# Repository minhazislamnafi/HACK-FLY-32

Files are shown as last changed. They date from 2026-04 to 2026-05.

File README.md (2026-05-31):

# HACK FLY 32 (3 inch fpv drone using esp32 s3)

A compact 3-inch 3D printed FPV drone designed for efficiency, stability, and extended flight time. This project features a custom-built flight controller, ExpressLRS (ELRS) communication, and GPS support, all running on Betaflight firmware.






HACK FLY ZINE(2)

**[Zine link](/docs/ZINE/HACK%20FLY%20ZINE.pdf)**

⚠️ Disclaimer
The use and operation of this drone may require licenses in certain countries. This project is experimental and provided without any guarantee of safety or reliability and it's under the [CERN Open Hardware Licence version 2-Strongly reciprocal ](/license), and the firmware ESP-FLY is under the MIT license.

USE AT YOUR OWN RISK.

# Specifications

Frame Size: 3-inch.

Motors: 1104 – 4300KV.

Propeller: Gemfan 3018 bi-blade.

Battery Support: 2S – 3S LiPo.

suggested battery: (900-1500)mah 3s lipo.

Flight Controller: Custom-designed FC.

Firmware: Betaflight.

RC Protocol: ExpressLRS (ELRS)

Navigation: GPS supported.

gps compatibility: any 15*15mm gps (Hglrs m100 mini suggested)

Use Case: Long-range FPV, exploration, and experimental flight testing.

# Why HACK FLY?

A custom hardware and PCB that gives you your own way to add spice to it.
Also compatible with BetaFlight (you can achieve very agile and stable flight characteristics). Supports all types of Radio RX protocols: PPM, SBUS, IBUS, and CRSF Receivers.
If you combine it with a high-performance 18650 Li-ion battery (like Molicel PB28A,Eve 30pl,Ampace jp30 or Sony vt6), you can get over 10 minutes of flight time.

Who didn't want his drone to be repairable? The 3D-printed frame gives you that flexibility.
Break the frame in a crash? Just print another. Cost? less than 1$ even if you use PETG-CF.

# Documentation
In this repository, you can find 3D printable STL files, Garber and all the other
files to build your own flight controller and Drone frame. 
For flashing the latest Betaflight to the Flight controller visit rtlopez/esp-fc repo- 
**https://github.com/rtlopez/esp-fc**.

Join our **[Discord Channel](https://discord.gg/Ff5Q2nz4)** to get any kind of help.

# Quick Start

## Requirements

## Hardware:

* Seeed Studio Xiao ESP32 S3(https://www.seeedstudio.com/XIAO-ESP32S3-p-5627.html)
* 1104 4300kv mottor x4 (https://s.click.aliexpress.com/e/_c4sG0n0N)
* 2-3S micro 8A ESC x4 (https://s.click.aliexpress.com/e/_c4ShBcjr)
> [!IMPORTANT]
> **If you also want build your own 4in1 esc**, Visit this repo- **https://github.com/minhazislamnafi/Nano-2-3s-AM32-ESC**.
* Gemfan 3018 bi-blade × 2 pair (https://s.click.aliexpress.com/e/_c34qvZlJ)
* Hglrc m100 mini GPS (https://s.click.aliexpress.com/e/_c4F9Fw8h)
* HGLRC Zeus Nano VTX 350mW (https://s.click.aliexpress.com/e/_c3wNfnSD)
* 2.54mm Round Hole Needle Female & Male Pin Header (https://s.click.aliexpress.com/e/_c327hfoV)

**Components:**

* Mpu6050M QFN-24 (https://s.click.aliexpress.com/e/_c2JBpdQt)
* 0402 10uH inductor (https://s.click.aliexpress.com/e/_c3vbFmHj)
* Some 0603 size Resistors and capacitors [**Checkout Bill of material**](/Flight%20Controller/PCB/BOM_HACK_FLY_V1.2_2026-04-11.csv)
(https://a.aliexpress.com/_c3XHJm1T)
* 0805 size red & green led ×2
(https://s.click.aliexpress.com/e/_c3fRfz0V)

## For detailed parts list and prices follow [BOM](docs/Bill%20of%20material/BOM.md) ##

## PCB

Use JLCPCB if you're in ASIA or PCBWAY if you're in America. Also, find what manufacturer is better for you. 
If you just want to get Flight controller PCB then use this [**GERBER file**](/Flight%20Controller/PCB/Gerber_HACK_FLY_PCB_V1.2_2026-04-11.zip). Download it and place order.
Or if you just want to build your own PCB, then follow this [**Schematic**](/Flight%20Controller/PCB/Schematic_HACK_FLY_2026-04-11.svg).
fc 2 bg2

## 3D printed parts

1000042196-Photoroom

## Full Onshape CAD [link](https://cad.onshape.com/documents/91570ca427478f6ae70e01eb/w/492acaa76972d9ee5b32506f/e/992fe092f0691e5ff67f2b14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)/[Full assembly](https://cad.onshape.com/documents/91570ca427478f6ae70e01eb/w/492acaa76972d9ee5b32506f/e/0d19368f0521a092eb10a81c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)

To print all the parts for the HACK FLY frame, please **USE-**

**PETG or ABS** - [Top plate](/Drone%20Frame/Top%20Plate/Top%20plate.stl), [Bottom plate](/Drone%20Frame/Bottom%20plate).(**better to use PETG-CF**)

**TPU** - [Camera mount](/Drone%20Frame/Camera%20Mount/Camera%20mount%20right.stl), [GPS mount](/Drone%20Frame/GPS%20mount/GPS%20mount.stl), [VTXantena mount](/Drone%20Frame/Vtx%20antena%20mount/Antenna%20mount.stl).

## Wiring Diagram ##
wiring_diagram

## AFTER EVERYTHING IS DONE SOURCING, FOLLOW THESE STEPS ##

**1. Spend some money $$ to buy the parts mentioned in [BOM](docs/Bill%20of%20material/BOM.md).**

**2. Order the Flight controller PCB using this [GERBER file](/Flight%20Controller/PCB/Gerber_HACK_FLY_PCB_V1.2_2026-04-11.zip).**

**3. Solder the SMD components of the PCB by hand ;) Or just order the PCBs with SMT services.**

**4. Using the wiring diagram, solder the ESCs and battery connector to the PCB.**

**5. crucial step: assemble everything. ( I will add every assembly step, once I have built IRL:)**

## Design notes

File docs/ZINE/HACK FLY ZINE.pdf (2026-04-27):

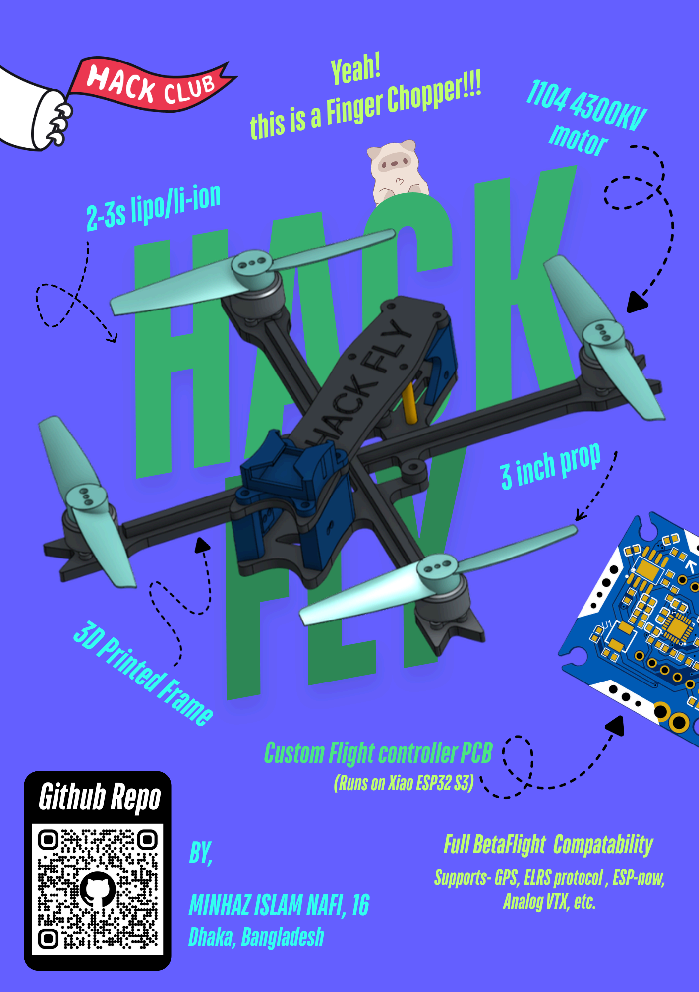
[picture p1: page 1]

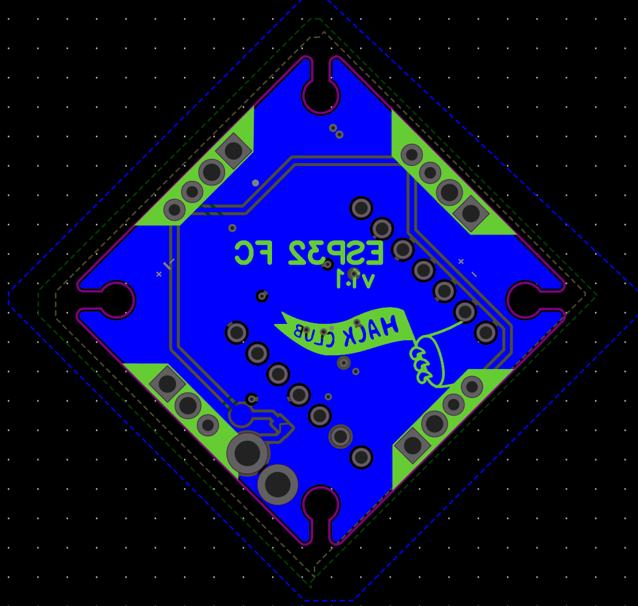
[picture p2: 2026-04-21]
docs/Images/FC_PCB_back.png

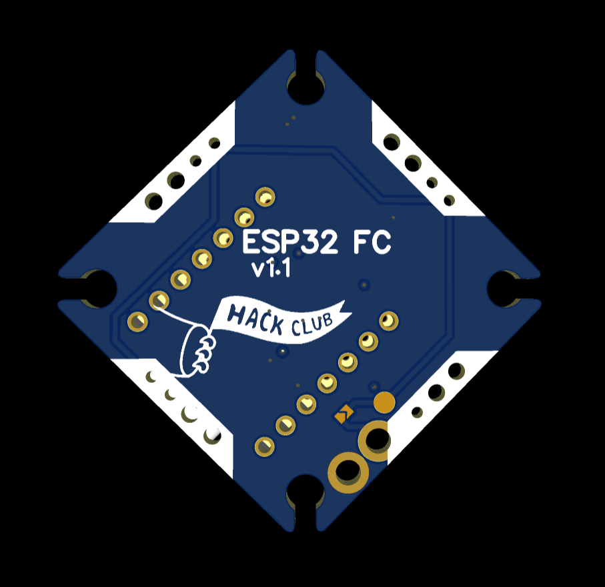
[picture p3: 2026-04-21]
docs/Images/FC_PCB_render_back.png

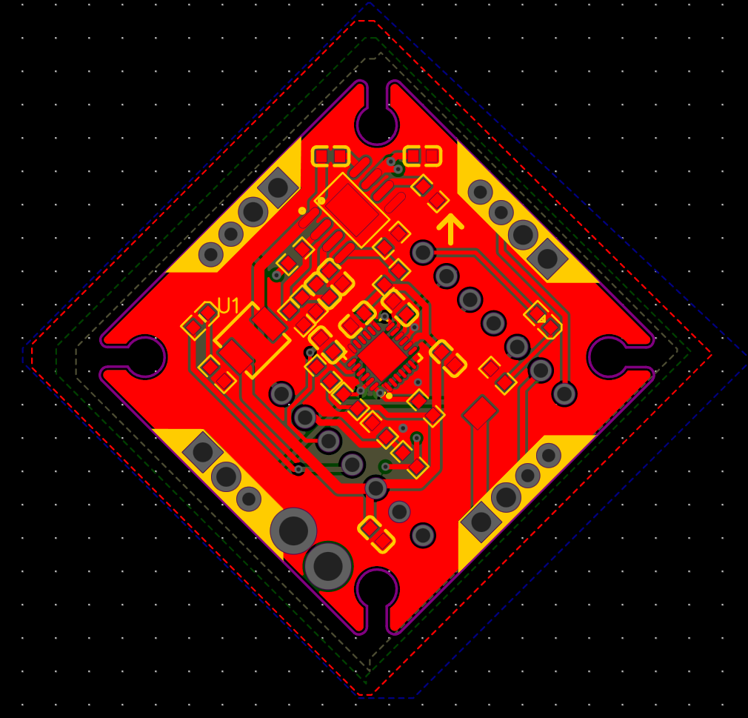
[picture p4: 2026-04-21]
docs/Images/FC_PCB_front.png

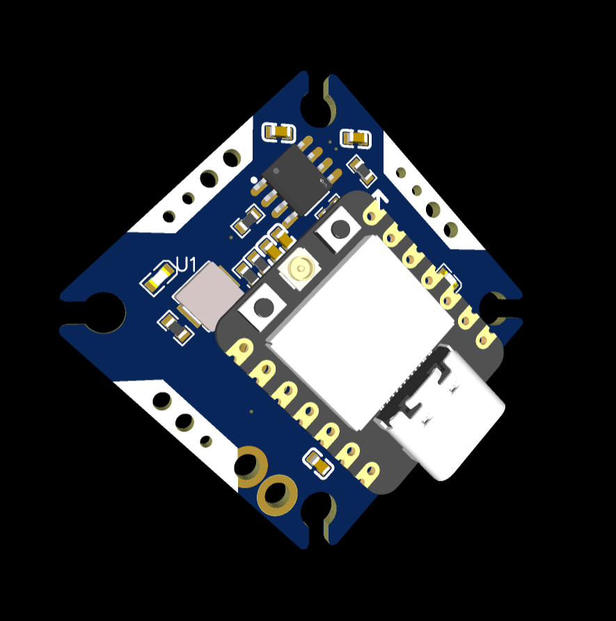
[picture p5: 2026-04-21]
docs/Images/FC_PCB_render_front.png

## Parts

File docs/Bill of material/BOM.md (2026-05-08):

# BOM #

The quantity of parts marked **(*)** is the lowest they sell. This is not the actual requirement quantity.

| Name | Qty | footprint | Source | price (total)|
| --- | :---: | :---: | :---: | :---: |
|  |  |  |  |  |
|  |  |  |  |  |
| **(For flight controller)** |  |  |  |  |
|  |  |  |  |  |
| `Seeed Studio Xiao ESP32 S3` | 1 | | [Seeed Studio](https://www.seeedstudio.com/XIAO-ESP32S3-p-5627.html) | 7.50$ |
| `Mpu6050M QFN-24` | *2 | QFN-24 | [AliExpress](https://s.click.aliexpress.com/e/_c2JBpdQt)  | 3.40$ |
| `MP1584EN-LF` | 1 | SOIC-8 | [AliExpress](https://s.click.aliexpress.com/e/_c4m1MzqZ) | 3.00$ |
| `2.54mm Round Hole Needle Female & Male Pin Header` | 2 | 2.54mm*40p | [AliExpress](https://s.click.aliexpress.com/e/_c327hfoV) | 2.30$  |
| `0402 10uH inductor` | *10 | L0402 | [AliExpress](https://s.click.aliexpress.com/e/_c3vbFmHj) | 1.80$ |
| ``100nf cap`` | *50 | C0603 | [AliExpress](https://s.click.aliexpress.com/e/_c2zBG1P7) | 0.90$ |
| ``10uf cap``| *50 | C0603 | [AliExpress](https://s.click.aliexpress.com/e/_c3JfbJJL) | 1.90$ |
| ``220pf cap`` | *50 | C0603 | [AliExpress](https://s.click.aliexpress.com/e/_c2zBG1P7) | 0.90$ |
| ``Red &green LED`` | *200 | 0603 | [AliExpress](https://s.click.aliexpress.com/e/_c2uf5xmZ)  | 1.20$ |
| ``200`` | *100 | R0603 | [AliExpress](https://s.click.aliexpress.com/e/_c3cSR54l) | 0.65$ |
| ``10K`` | *100 | R0603 | [AliExpress](https://s.click.aliexpress.com/e/_c3cSR54l) | 0.65$ |
| ``100K`` | *100 | R0603 | [AliExpress](https://s.click.aliexpress.com/e/_c3cSR54l) | 0.65$ |
| ``200K`` | *100 | R0603 | [AliExpress](https://s.click.aliexpress.com/e/_c3cSR54l) | 0.65$ |
| ``24.9K`` | *100 | R0603 | [AliExpress](https://s.click.aliexpress.com/e/_c3cSR54l) | 0.65$ |
| ``64.1K`` | *100 | R0603 | [AliExpress](https://s.click.aliexpress.com/e/_c3cSR54l) | 0.65$ |
| ``124K`` | *100 | R0603 | [AliExpress](https://s.click.aliexpress.com/e/_c3cSR54l) | 0.65$ |
| ``40.2K`` | *100 | R0603 | [AliExpress](https://s.click.aliexpress.com/e/_c3cSR54l) | 0.65$ |
|  |  |  |  |  |
|  |  |  |  |  |
| **(For Drone it self)** |  |  |  |  |
|  |  |  |  |  |
| `1104 4300kv mottor` | 4 | | [AliExpress](https://s.click.aliexpress.com/e/_c4sG0n0N)  | 11.72$ |
| `2-3S micro 8A ESC` | 4 | | [AliExpress](https://s.click.aliexpress.com/e/_c4ShBcjr)  | 6.92$ |
| `Gemfan 3018 bi-blade` | 4 pair | | [AliExpress](https://s.click.aliexpress.com/e/_c34qvZlJ ) | 7.5$ |
| `2.4Ghz ELRS RX` | 1 |  | [AliExpress](https://a.aliexpress.com/_c4OytxWf) | 11.5 |
| `Hglrc m100 mini GPS` | 1 | | [AliExpress](https://s.click.aliexpress.com/e/_c4F9Fw8h)  | 15.6$ |
| `HGLRC Zeus Nano VTX 350mW` | 1 | | [AliExpress](https://s.click.aliexpress.com/e/_c3wNfnSD)| 26.8$ |
| `2mm*15mm Female to Female thread Brass Round Standoff` | *20 | | [ AliExpress](https://s.click.aliexpress.com/e/_c4UTr2UN)  | 1.95$ |
| `M1.4*6mm Cross Phillips Flat Head Countersunk Head Screw` | *100  | | [AliExpress](https://s.click.aliexpress.com/e/_c2ynEA9r ) | 0.85$ |
| `M2*6mm Phillips Truss Mushroom Head Screw` | *20 | | [AliExpress](https://s.click.aliexpress.com/e/_c3dtilIl) | 1.08$|
| `M2*12mm Harden Allen Hex Hexagon Screw` | *50 | | [AliExpress](https://s.click.aliexpress.com/e/_c34U4h6V)| 2.80$ |
|  |  |  | | |
|  |  |  | | |
| **PCB Manufacturing** | *5 |  | [JLCPCB](https://cart.jlcpcb.com/quote) | 2$ +shiping|
|  |  |  | | |
| **3D printing** | 1 |  | local vendor | ~2$ |
|  |  |  | | |
|  |  |  | | |
|  |  | **Esteemed Cost** | Around(**~105$**) | |

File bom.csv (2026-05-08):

Name | Qty | Footprint | Source | Unit Price | Price (total)
(For flight controller)
Seeed Studio Xiao ESP32 S3 | 1 |  | https://www.seeedstudio.com/XIAO-ESP32S3-p-5627.html | 7.50 | 7.50
Mpu6050M QFN-24 | 2 | QFN-24 | https://s.click.aliexpress.com/e/_c2JBpdQt | 1.70 | 3.40
MP1584EN-LF | 1 | SOIC-8 | https://s.click.aliexpress.com/e/_c4m1MzqZ | 3.00 | 3.00
2.54mm Round Hole Needle Female & Male Pin Header | 2 | 2.54mm*40p | https://s.click.aliexpress.com/e/_c327hfoV | 1.15 | 2.30
0402 10uH inductor | 10 | L0402 | https://s.click.aliexpress.com/e/_c3vbFmHj | 0.18 | 1.80
100nf cap | 50 | C0603 | https://s.click.aliexpress.com/e/_c2zBG1P7 | 0.018 | 0.90
10uf cap | 50 | C0603 | https://s.click.aliexpress.com/e/_c3JfbJJL | 0.038 | 1.90
220pf cap | 50 | C0603 | https://s.click.aliexpress.com/e/_c2zBG1P7 | 0.018 | 0.90
Red & green LED | 200 | 0603 | https://s.click.aliexpress.com/e/_c2uf5xmZ | 0.006 | 1.20
200 resistor | 100 | R0603 | https://s.click.aliexpress.com/e/_c3cSR54l | 0.0065 | 0.65
10K resistor | 100 | R0603 | https://s.click.aliexpress.com/e/_c3cSR54l | 0.0065 | 0.65
100K resistor | 100 | R0603 | https://s.click.aliexpress.com/e/_c3cSR54l | 0.0065 | 0.65
200K resistor | 100 | R0603 | https://s.click.aliexpress.com/e/_c3cSR54l | 0.0065 | 0.65
24.9K resistor | 100 | R0603 | https://s.click.aliexpress.com/e/_c3cSR54l | 0.0065 | 0.65
64.1K resistor | 100 | R0603 | https://s.click.aliexpress.com/e/_c3cSR54l | 0.0065 | 0.65
124K resistor | 100 | R0603 | https://s.click.aliexpress.com/e/_c3cSR54l | 0.0065 | 0.65
40.2K resistor | 100 | R0603 | https://s.click.aliexpress.com/e/_c3cSR54l | 0.0065 | 0.65
(For Drone itself)
1104 4300kv motor | 4 |  | https://s.click.aliexpress.com/e/_c4sG0n0N | 2.93 | 11.72
2-3S micro 8A ESC | 4 |  | https://s.click.aliexpress.com/e/_c4ShBcjr | 1.73 | 6.92
Gemfan 3018 bi-blade | 4 pair |  | https://s.click.aliexpress.com/e/_c34qvZlJ | 1.875 | 7.50
2.4Ghz ELRS RX | 1 |  | https://a.aliexpress.com/_c4OytxWf | 11.5 | 11.5
Hglrc m100 mini GPS | 1 |  | https://s.click.aliexpress.com/e/_c4F9Fw8h | 15.60 | 15.60
HGLRC Zeus Nano VTX 350mW | 1 |  | https://s.click.aliexpress.com/e/_c3wNfnSD | 26.80 | 26.80
2mm*15mm Female to Female thread Brass Round Standoff | 20 |  | https://s.click.aliexpress.com/e/_c4UTr2UN | 0.0975 | 1.95
M1.4*6mm Cross Phillips Flat Head Countersunk Head Screw | 100 |  | https://s.click.aliexpress.com/e/_c2ynEA9r | 0.0085 | 0.85
M2*6mm Phillips Truss Mushroom Head Screw | 20 |  | https://s.click.aliexpress.com/e/_c3dtilIl | 0.054 | 1.08
M2*12mm Harden Allen Hex Hexagon Screw | 50 |  | https://s.click.aliexpress.com/e/_c34U4h6V | 0.056 | 2.80
PCB Manufacturing | 5 |  | https://cart.jlcpcb.com/quote | 0.40 | 2 + shipping
3D printing | 1 |  | local vendor | ~2 | ~2
Estimated Cost |  |  |  |  | ~115

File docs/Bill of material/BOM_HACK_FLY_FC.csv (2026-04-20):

ID | Name | Designator | Footprint | Quantity | Supplier | Supplier Part | Price
1 | 100nF | C1,C2,C3,C4,C5 | C0603 | 5 | LCSC | C138344
2 | 10uF | C6 | C0603 | 1 | LCSC | C138344
3 | 220pf | C7,C9 | C0603 | 2 | LCSC | C138344
4 | ns | C8 | C0603 | 1 | LCSC | C138344
5 | LED-0603 | LED1 | LED0603-RD | 1 | LCSC | C9900020572
6 | 0603,0M6MM_HEIGHTCHIPLED,GREEN | LED2 | LED0603-RD_GREEN | 1 | LCSC | C9900023193
7 | 200Ω | R1,R2 | R0603 | 2 | LCSC | C2479157 | 0.018
8 | 10kΩ | R3,R4,R5,R6,R7 | R0603 | 5 | LCSC | C4109781 | 0.231
9 | 100kΩ | R8 | R0603 | 1 | LCSC | C4109781 | 0.231
10 | 200kΩ | R9 | R0603 | 1 | LCSC | C4109781 | 0.231
11 | 24.9kΩ | R10 | R0603 | 1 | LCSC | C4109781 | 0.231
12 | 68.1kΩ | R11 | R0603 | 1 | LCSC | C4109781 | 0.231
13 | 124kΩ | R12 | R0603 | 1 | LCSC | C4109781 | 0.231
14 | 40.2kΩ | R13 | R0603 | 1 | LCSC | C4109781 | 0.231
15 | 10uH | U1 | IND-SMD_L4.5-W4.1_SL0420 | 1 | LCSC | C22463809 | 0.121
16 | MPU6050-YJLTY | U2 | QFN-24_L4.0-W4.0-P0.50-BL-EP2.7 | 1 | LCSC | C2912107
17 | XIAO ESP32 S3 | U3 | CONN-SMD_XIAO_ESP32C3 | 1 | LCSC | C19189385
18 | MP1584EN-LF | U4 | SOIC-8_L4.9-W3.9-P1.27-LS6.0-BL-EP3.3-1 | 1 | LCSC | C21999497

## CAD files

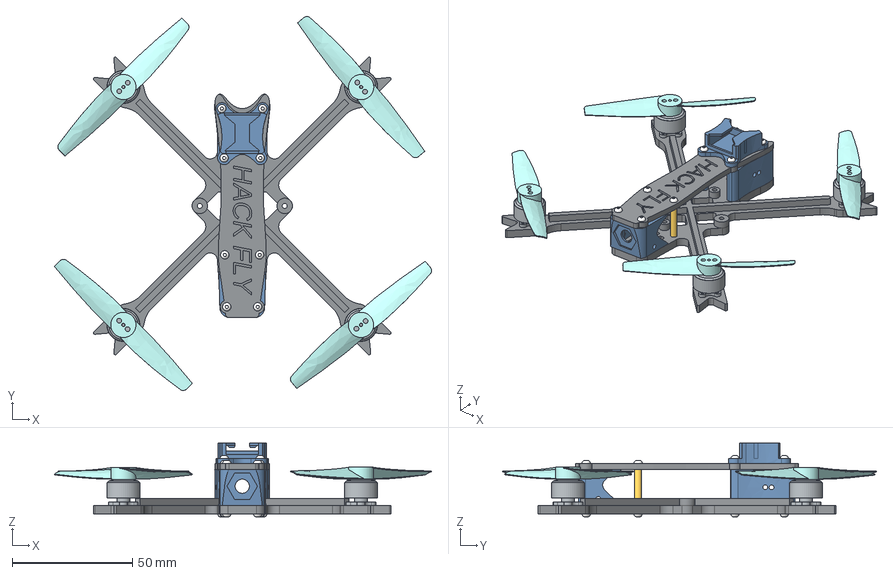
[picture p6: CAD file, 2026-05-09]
Drone Frame/CAD Source file/HACK_FLY_full_Assembly.step
157.0 x 155.7 x 30.8 mm
Button M2-8 x 16

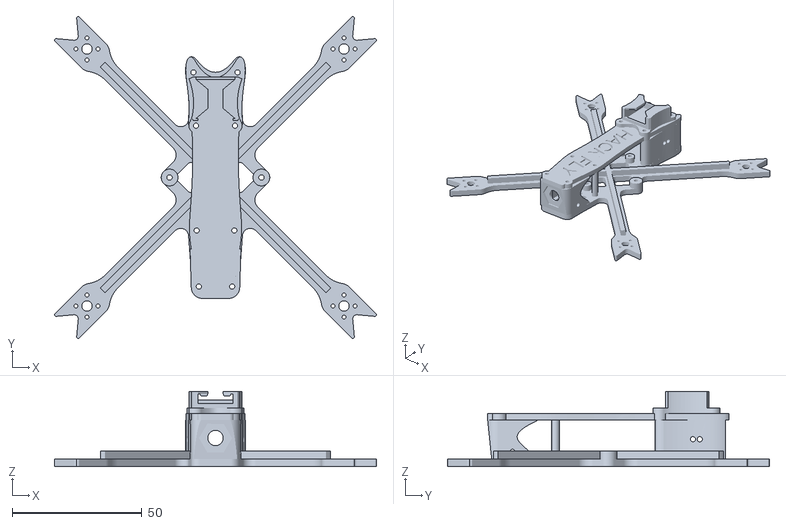
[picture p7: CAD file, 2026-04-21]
Drone Frame/CAD Source file/HACK_FLY_FULL.stl
124.0 x 124.0 x 29.0

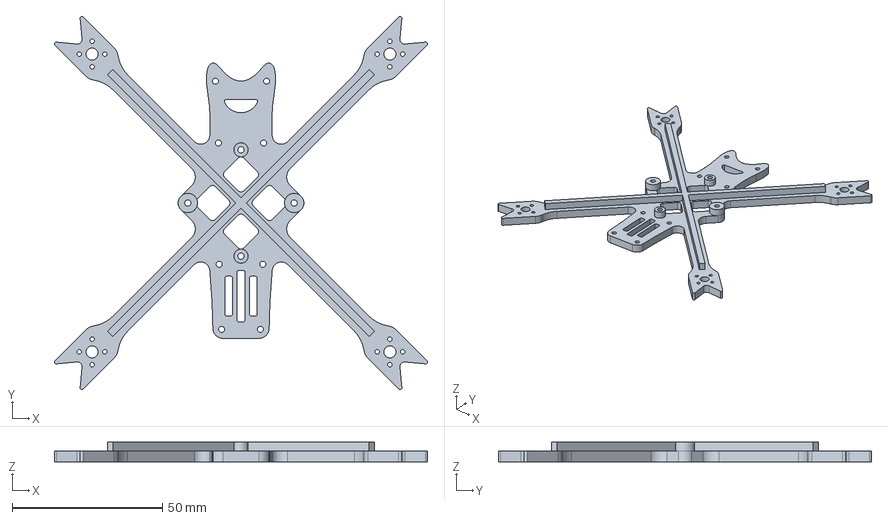
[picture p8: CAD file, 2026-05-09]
Drone Frame/Bottom plate/Bottom plate.step
124.0 x 124.0 x 6.50 mm

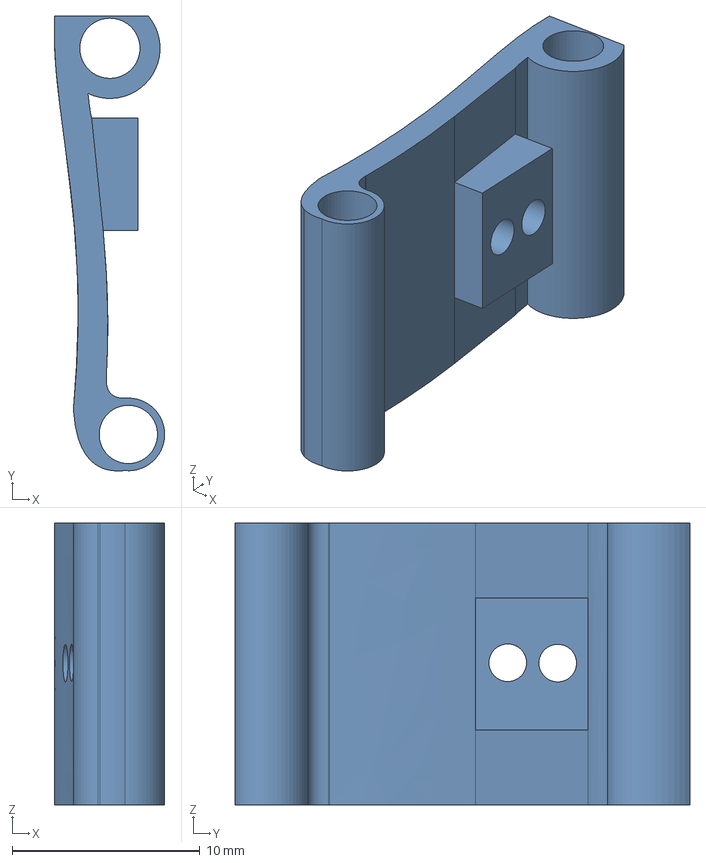
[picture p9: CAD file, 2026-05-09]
Drone Frame/Camera Mount/Camera mount-left.step
5.87 x 24.2 x 15.0 mm

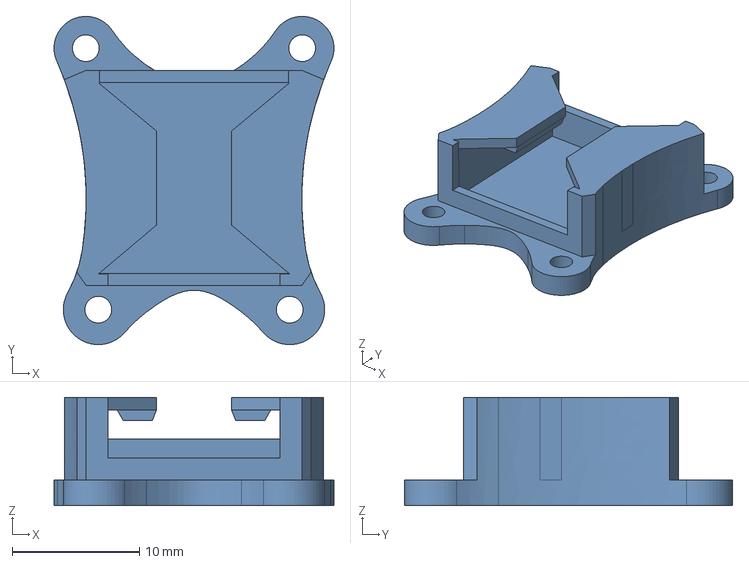
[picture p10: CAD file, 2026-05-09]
Drone Frame/GPS mount/GPS mount.step
22.0 x 25.8 x 8.50 mm

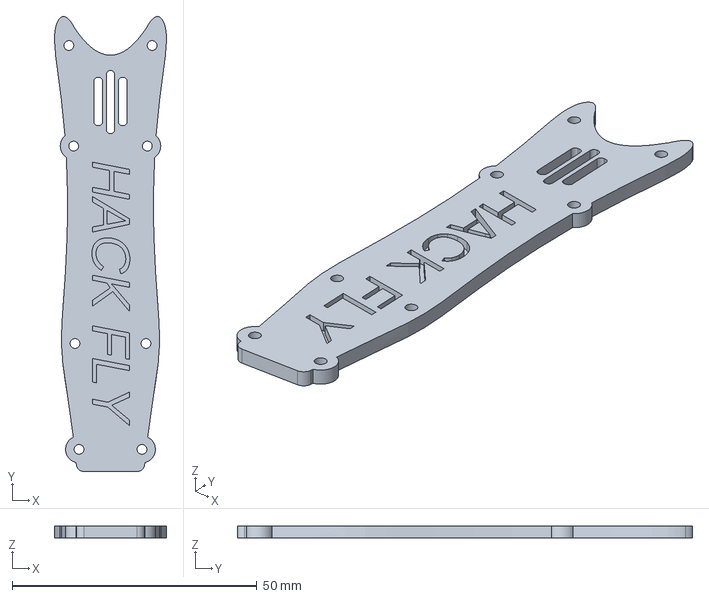
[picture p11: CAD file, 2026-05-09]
Drone Frame/Top Plate/Top plate.step
22.9 x 93.0 x 2.50 mm

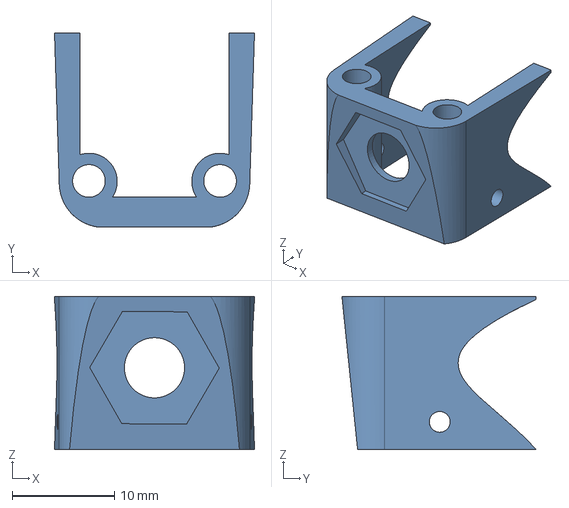
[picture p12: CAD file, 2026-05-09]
Drone Frame/Vtx antena mount/Antenna mount.step
19.6 x 19.0 x 15.0 mm

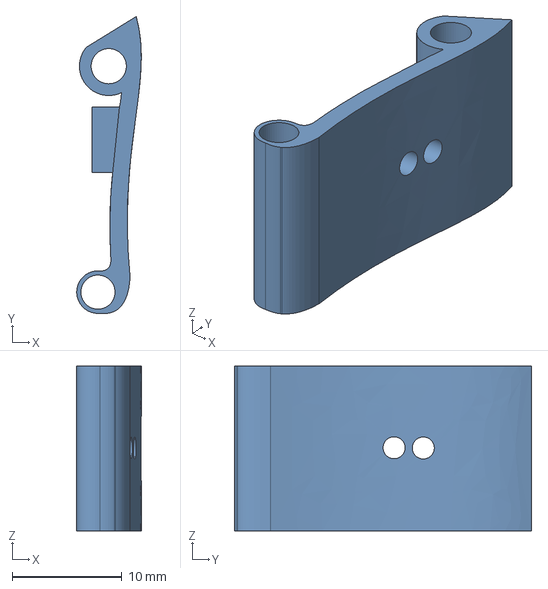
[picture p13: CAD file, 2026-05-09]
Drone Frame/Camera Mount/Camera mount-right.step
5.87 x 27.0 x 15.0 mm

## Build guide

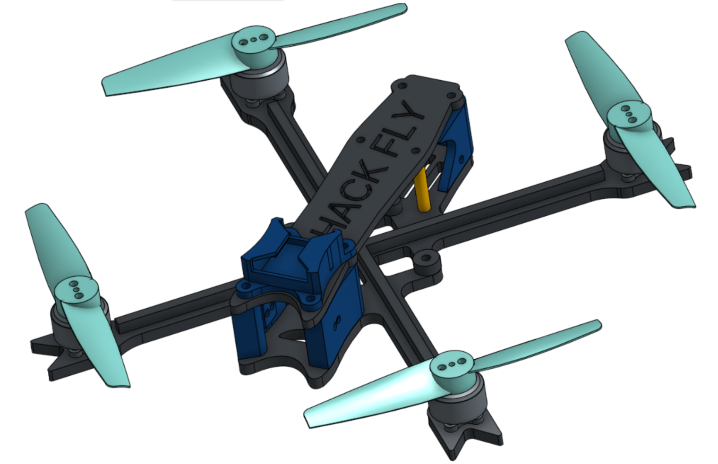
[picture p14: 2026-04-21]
docs/Images/Drone_frame_full_assembly.png

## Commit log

2026-04-14 Add pin header to components list in README
    Added a new component to the list of required parts.
2026-04-14 Add PCB manufacturing info and GERBER file link
    Added PCB manufacturing recommendations and a link to the GERBER file.
2026-04-14 Enhance PCB section with download and schematic links
    Added instructions for downloading the GERBER file and building a custom PCB.
2026-04-17 Add BOM for flight controller in hardware documentation
2026-04-17 Fix spelling and add BOM for Drone Frame
    Corrected the spelling of 'controller' in the BOM section and added a new BOM section for the Drone Frame.
2026-04-17 Fix BOM formatting and typo in hardware.md
    Removed a duplicate header and corrected a typo in the BOM.
2026-04-17 Change BOM header from '##' to '#' and format table
2026-04-17 Update BOM with additional hardware details
2026-04-20 Fix formatting of Brass Round Standoff entry
2026-04-20 Revise BOM with pricing and quantity details
    Updated hardware bill of materials with prices and quantities.
2026-04-20 Update hardware costs and add PCB manufacturing info
2026-04-20 Fix formatting and update links in hardware BOM
2026-04-21 Create BOM
2026-04-21 Add BOM.md file to documentation
2026-04-21 Add Bill of Materials with parts and pricing
    Added a detailed Bill of Materials (BOM) for the project, including parts, quantities, sources, and prices.
2026-04-27 Add Onshape link for HACK_FLY CAD source
2026-05-09 Create HACK_FLY_Full Onshape Assembly

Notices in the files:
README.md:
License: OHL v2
